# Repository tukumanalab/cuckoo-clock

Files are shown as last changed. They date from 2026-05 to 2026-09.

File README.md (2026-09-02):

# 鳩時計カムジェネレーター

3Dプリンターで製作できるオルゴール（ミュージックボックス）用カムの STL ファイルを、ブラウザ上で生成する Web アプリです。

**[大人の科学マガジン　あたらしい鳩時計](https://hon.gakken.jp/book/1575098600)（学研）の付録に付いているオルゴール機構で使えるカムのジェネレーターです。** このキットの機構にそのままセットできる寸法でカムを出力します。

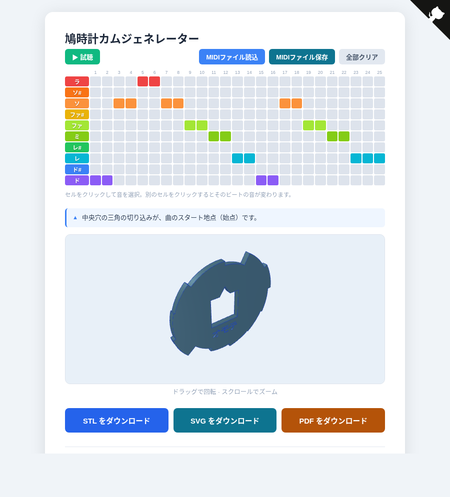
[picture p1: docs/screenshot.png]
アプリのスクリーンショット


## 概要

オルゴール機構の「琴爪（きんそう）」は、カムの歯（突起）の高さに応じてどの音が鳴るかが決まります。このアプリでは 25 分割されたカムの各セクターに音符を割り当て、好みのメロディを奏でるカムを設計・出力できます。

## 使い方

1. ブラウザで `index.html` を開く（静的 HTTP サーバーで配信）
2. ピアノロールのセルをクリックして 25 ビートに音を割り当て
3. 「▶ 試聴」でメロディを Web Audio で確認
4. 「STL をダウンロード」で 3D プリント用ファイル（`melody_cam.stl`）を取得
5. 3D プリンターでプリントし、オルゴール機構にセット

### UI 要素

| 要素 | 内容 |
|---|---|
| ピアノロール | 縦軸＝10 段階の音（半音階・ラ〜ド）、横軸＝25 ビート |
| セルクリック | そのビートに音を割り当て／同じセルを再クリックで休符（直前の音と同じ径） |
| ▶ 試聴 | 全 25 ビートを再生（triangle 波）。テンポは初期 ♩=300、MIDI 読込後はそのテンポ |
| MIDIファイル読込 | MIDI（SMF）を読み込んでピアノロールへ反映（1 拍 = 4 分音符、ラ〜ドへオクターブ畳み込み） |
| MIDIファイル保存 | 現在のメロディを MIDI（`melody.midi`、25/4 拍子・試聴と同じテンポ）として書き出し |
| 全部クリア | 全ビートを休符にリセット |
| 3D プレビュー | ドラッグで回転 · スクロールでズーム |
| STL をダウンロード | 現在のメロディをカム形状（STL）として書き出し |

## カム仕様

| パラメーター | 値 |
|---|---|
| セクター数 | 25 等分 |
| 厚さ | 1.8 mm |
| 中央穴 | 10.5 × 10.5 mm 正方形 |
| 開始マーカー | 正方形穴の +X 方向の壁に V字溝（幅 1.0mm・深さ 1.5mm） |

中央の正方形穴は、オルゴール機構の回転軸に取り付けるためのものです。V字溝がある側がセクター 1（メロディの最初の音）の開始位置です。

## 歯の高さ（外径）と音階の関係

オルゴール機構では**外径が大きいほど高い音**が鳴ります。琴爪の長さが外径によって決まり、短い琴爪ほど高周波で振動するためです。

この機構は **φ30〜φ40mm の範囲であれば、どの外径でも音が鳴る** 連続構造になっています。離散的な「5 つの琴爪」が並んでいるわけではなく、歯の高さに応じてピッチが連続的に変化します。本アプリではこの範囲を 10 段階に等分割して、半音階の「鍵盤」としてピアノロールに並べています。

| ノート番号 | 階名 | 外径 | 半径（コード値） | 試聴音（ドレミ／音名／周波数） |
|---|---|---|---|---|
| 0 | ラ | φ40.00 mm | 20.000 mm | ラ4 / A4 / 440 Hz |
| 1 | ソ# | φ38.75 mm | 19.375 mm | ソ#4 / G#4 / 415 Hz |
| 2 | ソ | φ37.50 mm | 18.750 mm | ソ4 / G4 / 392 Hz |
| 3 | ファ# | φ36.67 mm | 18.333 mm | ファ#4 / F#4 / 370 Hz |
| 4 | ファ | φ35.83 mm | 17.917 mm | ファ4 / F4 / 349 Hz |
| 5 | ミ | φ35.00 mm | 17.500 mm | ミ4 / E4 / 330 Hz |
| 6 | レ# | φ33.75 mm | 16.875 mm | レ#4 / D#4 / 311 Hz |
| 7 | レ | φ32.50 mm | 16.250 mm | レ4 / D4 / 294 Hz |
| 8 | ド# | φ31.25 mm | 15.625 mm | ド#4 / C#4 / 277 Hz |
| 9 | ド | φ30.00 mm | 15.000 mm | ド4 / C4 / 262 Hz |

### ⚠ 試聴音と実機の音は別物です

ピアノロールで「ラ」と打ち込むと、ブラウザは **A4＝440Hz** を鳴らしますが、実機のカムが鳴らすのは **A4 ではありません**。試聴と実機の音は、次の 2 つの点で違います。

#### ① オクターブが約 3 つ違う

実機の音は **第 7 オクターブ**（2400〜3800Hz）の高音域です。機構が小型で琴爪が短いため、固有振動数が高くなります。ブラウザ試聴は耳に優しい **第 4 オクターブ**（中央ハ周辺、262〜440Hz）に置いていて、メロディの形（上がる／下がる／繰り返し）を確認するためのものです。

#### ② 音の並び方が違う（試聴と実機で「ラ」が指す音が違う）

ピアノロールの「ラ」「ソ」「ミ」「ド」… は **ピアノの白鍵・黒鍵に揃えた音の並び**（音楽でいう「平均律」）です。これは人間の耳に馴染みがあり、メロディが綺麗に聞こえるように人工的に整えてあります。

一方、実機は金属パーツを物理的に振動させて鳴らす機構なので、出る音は機構の形状や材質で勝手に決まります。φ40mm を「ラ」のつもりで打ち込んでも、実機が出すのは「ラ（A）」ではなく **少し高い「シ♭（Bb）」**。同様に「ミ」のつもりが「ソ#」、「ド」のつもりが「レ」のあたり、というふうに、**全部ズレた音名で鳴ります**。

#### でもこれで OK な理由

「ピアノロールの音名と実機の音が一致しないなら、試聴は何のためにあるの？」と思うかもしれません。これで OK な理由は：

- **メロディは「音の名前」ではなく「音の上下のパターン」で認識される。** たとえば「ド ド ソ ソ ラ ラ ソ」を全体的に半音や全音ずらしても、上がる場所・下がる場所・繰り返す場所が同じなら、人は **同じキラキラ星** だと聞き取れます。カラオケで自分のキーに合わせて歌っても曲が変わらないのと同じです。
- アプリの試聴も実機も、**外径が大きい歯ほど高い音、小さい歯ほど低い音** という性質は共通しています。だから「ピアノロールで聞いて気持ちよく流れたメロディ」は、実機でもだいたい同じ上下のパターンで流れます。
- 試聴の役割は「**メロディの形（ジングルの感じ）**」を耳で確認すること。「**絶対的にこの音が鳴る**」ことを約束するものではありません。

なお、実機の音は平均律ではないので、**ピアノロール上の音間隔と実機の音間隔は完全には一致しません。** たとえば試聴で「ドとソは 5 度離れている」と聞こえても、実機では同じ 2 か所が「5 度よりやや狭い」「半音ほど広い」など微妙にズレることがあります。それでも「上がる・下がる・繰り返す」の骨格は保たれるので、メロディとして認識できる、というのが基本的な発想です。

### 休符の扱い

カム上に「休符」という概念はありません。エディター上で何も選択していないビート（休符）は、STL 出力時に**直前のビートと同じ外径**として扱われます。これによりすべてのセクターが機構に確実にかかり、同じ音が連続して鳴る形になります。

### 実測値（参考）

5 つの代表的な外径について、単音テストカムを実機にかけてマイクで録音・解析した結果です。この 5 点は機構が出せる音の **代表サンプル** であり、間の径（例：φ36.67mm）でも音は鳴ります（連続的に変化します）。

| 外径 | 実測音名（ドレミ／音名） | 代表周波数 | 備考 |
|---|---|---|---|
| φ40mm | **シ♭7（ラ#7） / Bb7（A#7）** | ~3709 Hz | ボディ共鳴との差分で同定 |
| φ37.5mm | ファ#7 / F#7（参考値） | ~2980 Hz | 5音サイクルカムからの推定 |
| φ35mm | **ソ#7（ラ♭7） / G#7（Ab7）** | ~3406 Hz | 非常に安定した測定値 |
| φ32.5mm | 未同定 | 不安定 | サイクルごとにスペクトル変動 |
| φ30mm | **レ7〜レ#7 / D7〜D#7** | ~2420 Hz | D7 より約 +30¢ 高め |

- φ40mm と φ35mm はどちらも G#7 付近（~3350 Hz）に強いピークを持ちますが、これは機構本体の**ボディ共鳴（胴鳴り）**です。φ40mm 固有の音は差分スペクトルで求めた Bb7（~3710 Hz）です。
- φ32.5mm の音名が「未同定」なのは、機構が鳴らないからではなく、サイクルごとに測定スペクトルが変動して安定したピークを特定できなかったためです。
- 解析ツール: Python + soundfile + scipy（macOS `afconvert` で m4a → WAV 変換）

## デフォルトメロディ（キラキラ星）

起動時のメロディは「キラキラ星」（25 ビート）です：

```
ビート 1– 8: ド ド ソ ソ ラ ラ ソ ソ
ビート 9–16: ファ ファ ミ ミ レ レ ド ド
ビート17–25: ソ ソ ファ ファ ミ ミ レ レ レ
```

## ファイル構成

```
cuckoo-clock/
├── index.html        # HTML マークアップ
├── style.css         # スタイルシート
├── app.js            # Three.js プレビュー + STL 生成 + UI ロジック
├── docs/
│   └── screenshot.png  # README 用スクリーンショット
└── README.md         # このファイル
```

## 動作環境

- モダンブラウザ（Chrome / Firefox / Safari / Edge）
- ES Modules と importmap をサポートする環境
- Three.js は CDN（jsdelivr）から読み込み（インターネット接続が必要）

ローカルで動作させる場合は HTTP サーバーが必要です：

```bash
python3 -m http.server 8080
# または
npx serve .
```

## ライセンス

MIT

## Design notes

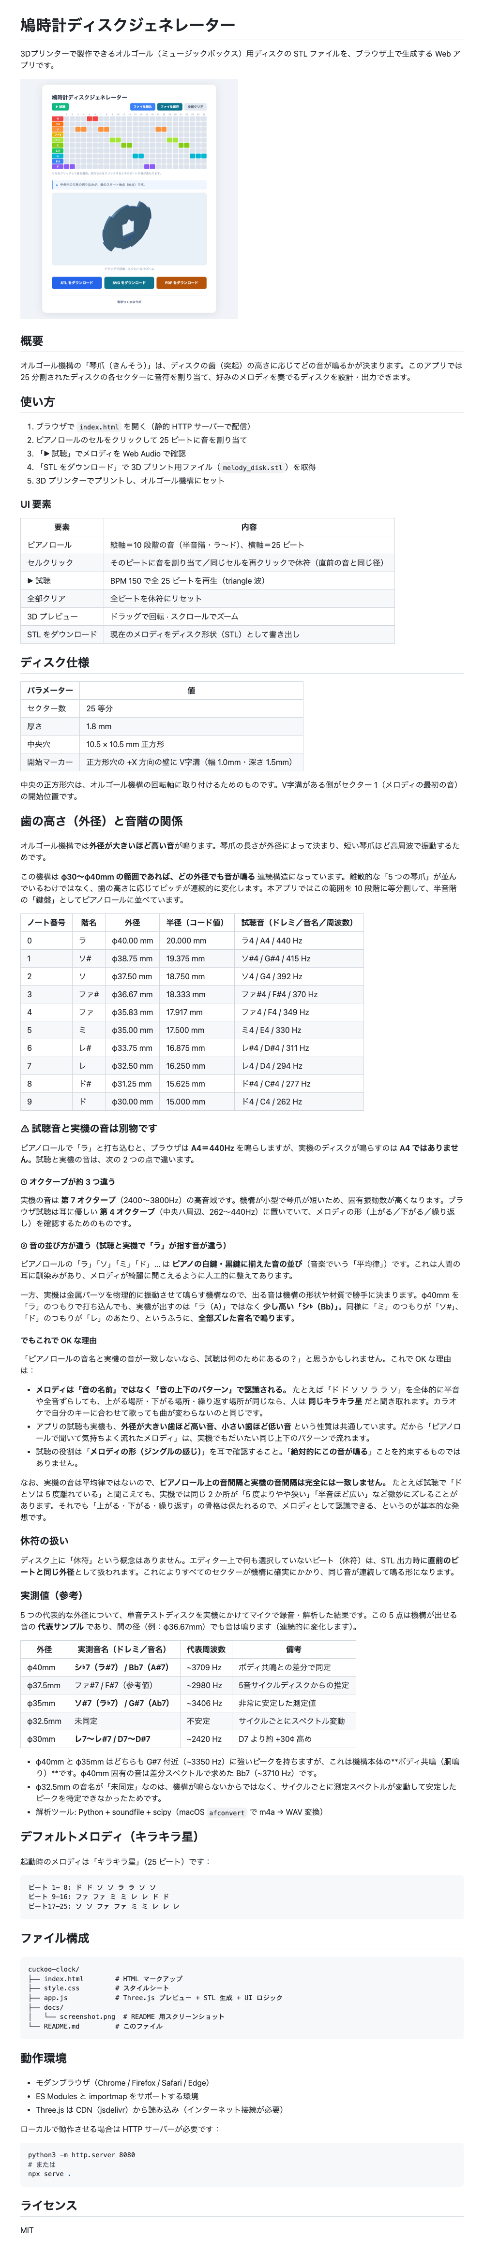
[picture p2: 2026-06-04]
docs/github.png

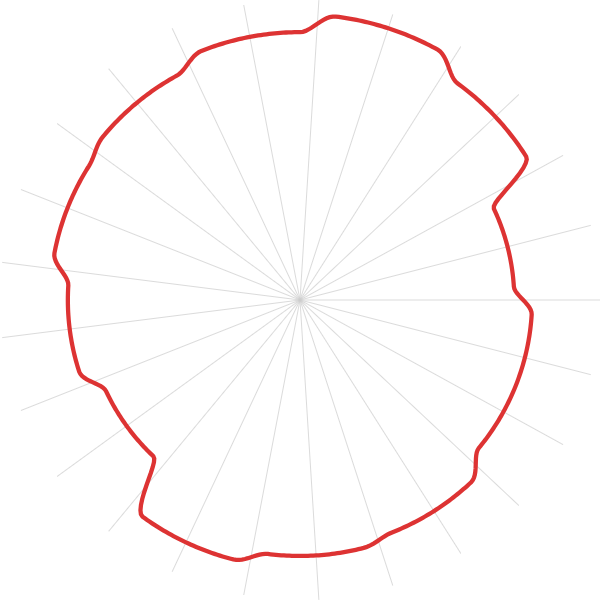
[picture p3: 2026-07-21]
pr-images/cam-svg-outline.png

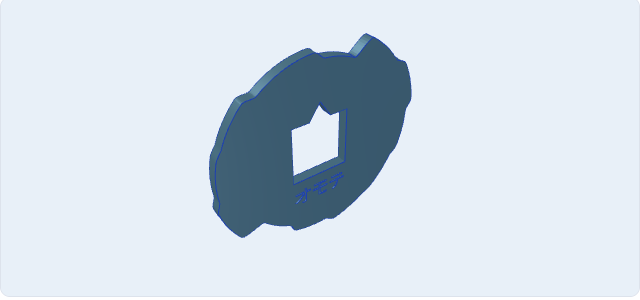
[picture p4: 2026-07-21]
pr-images/cam-3d-preview.png

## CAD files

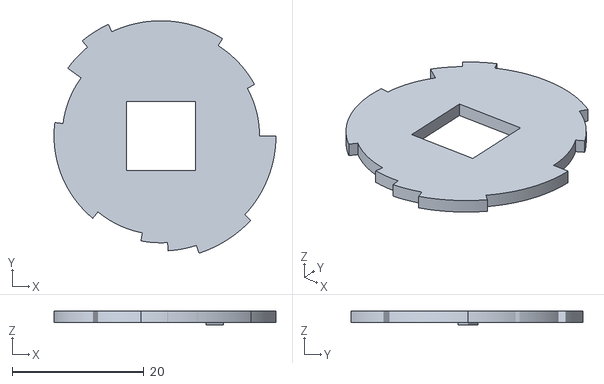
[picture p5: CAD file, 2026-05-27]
stl/poppo.stl
33.8 x 35.3 x 2.20

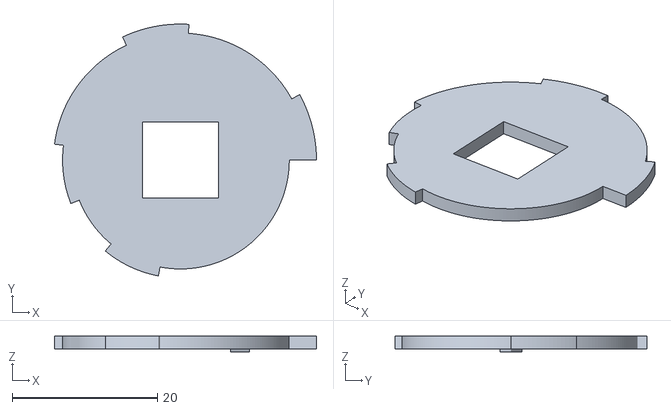
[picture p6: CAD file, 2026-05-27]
stl/kakko.stl
36.1 x 34.7 x 2.20

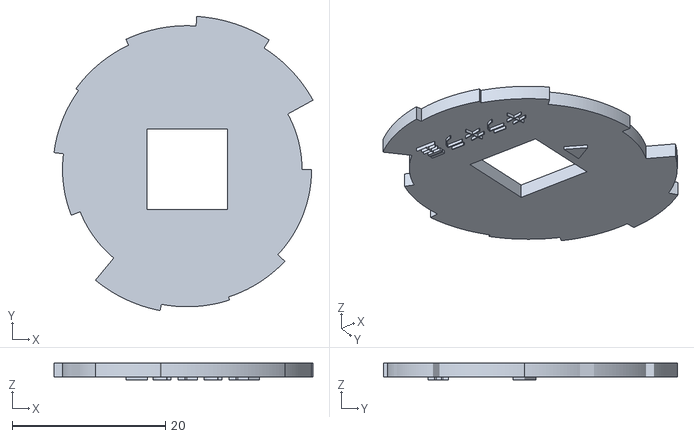
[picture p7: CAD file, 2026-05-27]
stl/kirakira.stl
33.8 x 38.4 x 2.20

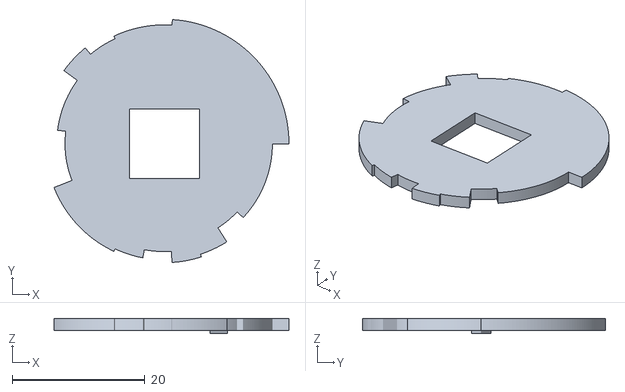
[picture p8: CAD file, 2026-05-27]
stl/hinotori.stl
35.4 x 36.6 x 2.20

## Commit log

2026-05-22 Initial commit: music box disk STL generator
    - STL generator for 3D-printable music box (オルゴール) disks
    - Three.js interactive 3D preview
    - Melody mode with 24-beat sequencer (キラキラ星 default)
    - Start groove marker on square center hole at sector 0
    - Single-note test disks (φ40/35/30mm)
    - CSS and JS split into separate files
2026-05-22 Rename app title to 鳩時計ディスクジェネレーター
2026-05-22 Show solfège (ドレミ) on melody beat buttons
2026-05-22 Remove single-note test disk buttons (φ40/35/30mm)
2026-05-22 ピアノロール UI を実装し12音クロマチック対応・休符廃止
    - ピアノロール UI（縦12音×横25拍のステップシーケンサー）を実装
    - 12音クロマチックスケール（ド〜シ）をサポート：各音に固有のディスク外径を設定
    - ファ/ファ#/ソ#/レ#/ド# は既知5点間を半音基準で線形補間
    - シ/ラ# は物理限界（φ40mm）に頭打ち
    - 休符廃止：各ビートは常に音を持つ（クリックで音を選択）
    - キラキラ星メロディを25拍・正しい音階に更新（ファを含む）
    - スペックテーブルを削除
    - ピアノロールのはみ出し修正：グリッド列数をJSで動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
2026-05-22 ラ# とシを音リストから削除（物理的に出力不可）
    10音クロマチック（ラ〜ド）に変更。キラキラ星のインデックスも更新。
2026-05-22 最後のビートを休符に変更・キラキラ星ダウンロードボタンを削除
    - DEFAULT_MELODY の最終ビート(25番)を休符(-1)に変更（STL出力時は直前のレを繰り返す）
    - 休符トグルを復活：アクティブなセルをクリックすると休符になる
    - キラキラ星専用ダウンロードボタン(dlTwinkle)を削除
2026-05-22 最終ビートをレに変更
2026-05-22 「♪ キラキラ星」タイトルを非表示に
2026-05-22 コードを簡素化（349行→265行）
    - 未使用の markerObj / REST_R / getRadiiSeq / noteSeqToRadii / downloadSTL / playNote / getCtx を削除
    - generateSTL の customSeq / addMarker 引数を廃止（V溝マーカーは常時付与）
    - playBtn ハンドラーをインライン化、audioCtx を nullish assignment で初期化
    - downloadBtn ハンドラーをインライン化
2026-05-22 「全部クリア」ボタンを追加
    全ビートを休符にリセットするボタンを試聴ボタンの隣に配置。
2026-05-23 README を現状のコードに合わせて更新
    10 段階半音階・25 ビート・単一画面 UI を反映し、試聴音にドレミ／音名／周波数を併記。
2026-05-23 README にアプリのスクリーンショットを追加
    ピアノロール（キラキラ星デフォルト）と 3D プレビューが写ったキャプチャを
    docs/screenshot.png として配置し、README 冒頭で表示。
2026-05-23 README の音階説明を訂正・スクリーンショットを半分にリサイズ
    機構は φ30〜φ40mm の連続構造で、どの外径でも音が鳴ることを明記。
    試聴音（平均律・第 4 オクターブ）と実機音（機構固有音律・第 7 オクターブ）
    の差を 2 軸で整理。スクリーンショットは 1800×2200 → 900×1100 に縮小。
2026-05-23 平均律の説明を非音楽家向けに書き直し・キャプチャをさらに半分に
    「平均律」を「ピアノの鍵盤に揃えた音の並び」と言い換え、なぜ試聴と
    実機の音名がズレても OK なのかをカラオケのキー変更の例で説明。
    スクリーンショットは 900×1100 → 450×550 にリサイズ。
2026-05-23 実測値表にドレミ表記を併記
    シ♭7／ファ#7／ソ#7／レ7〜レ#7 を Bb7 / F#7 / G#7 / D7〜D#7 と
    並べて表示し、音楽記号に不慣れな読者にも読みやすく。
2026-05-27 表側を示す三角形マーカーを追加
    ディスク上面（表）の中央穴上方に正三角形の突起（辺長3mm・高さ0.4mm）を追加。
    STL出力・3Dプレビュー両方に反映。
2026-05-27 表面（z=0面）に「オモテ」の刻印を追加
2026-05-27 オモテ文字刻印を三角突起に変更（V字溝と同方向）
2026-05-27 裏面の三角突起とV字溝を削除、初期表示を表側に変更
2026-05-27 刻印テキスト入力機能を追加（日本語対応、リアルタイムプレビュー）
    - opentype.js + Noto Sans JP でテキストを3Dジオメトリ化
    - STLExporter に置き換えてテキスト含む全メッシュを出力
    - sp.closePath() → sp.currentPath?.closePath() で TypeError を修正
    - X座標を反転し鏡文字を修正（カメラ-Z視点の座標系補正）
    - フォント読み込み後に「キラキラ星」をデフォルト値として表示
2026-05-27 刻印テキスト入力機能を削除
2026-05-27 STLサンプルファイルを追加
    [hinotori.stl, kakko.stl, kirakira.stl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]
2026-05-27 poppo.stl を更新
    [poppo.stl]
2026-06-02 SVG ダウンロード機能を追加
    レーザーカットや型紙用に、ディスク外周輪郭と中央穴（V溝マーカー付き）を
    含む SVG を出力するボタンを追加。.DS_Store も gitignore に追加。
2026-06-02 SVG を塗りつぶしなしの枠線のみに変更
    レーザーカット/型紙用途に合わせ、fill を none にして外周輪郭と中央穴を
    カットライン（黒 0.1mm）だけで出力。fill-rule による穴抜きは不要のため削除。
2026-06-02 ドレミ txt 入出力・SVG/PDF 出力・始点/オモテ表示を追加
    - ドレミ txt の読み込み/保存（parseSolfege / melodyToSolfege）
    - 始点の三角切り込み（曲のスタート地点。中央穴 +X 側、サイズ調整）
    - 「オモテ」表示用の貫通穴を中心の下に追加（表面で正立、Arial Unicode から抽出）
    - 始点を画面の上（+Y）に向ける表示回転（3D / SVG / PDF）
    - 枠データの SVG / PDF ダウンロード（PDF は A4 左上・原寸・表面像）
    - PDF 楽譜→ドレミ判読ロジックを CLAUDE.md に記録、sound_files/ に AMA2・FAN2 を配置
    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
2026-06-03 GitHub リボンとフッターリンクを追加
2026-06-04 ボタン名をファイル読込/ファイル保存に変更し README キャプチャを更新
    - index.html: 「ドレミ読込/ドレミ保存」→「ファイル読込/ファイル保存」
    - docs/screenshot.png: 最新 UI（始点バナー・SVG/PDF ボタン含む）で再撮影
    - CLAUDE.md: ボタン名の記述を更新
    - .claude/skills/run-app: アプリ起動とスクリーンショット撮影のプロジェクトスキルを追加
2026-06-04 README キャプチャを半分のサイズに縮小し README 全体のキャプチャを追加
    - docs/screenshot.png を 900x995 → 450x497 にリサイズ
    - README をレンダリングしたキャプチャを docs/github.png として追加
2026-06-04 メロディの読み書きをドレミ txt から MIDI ファイルに変更
    - ボタン名を「MIDIファイル読込」「MIDIファイル保存」に変更
    - SMF format 0/1 のパーサー（parseMidi）を実装。全トラックのノートオンを
    1 拍 = 4 分音符でセクターに割り当て、音のない拍は休符
    - 音高はオクターブ畳み込みでラ〜ド（A〜C の 10 半音）へ対応付け、
    範囲外・25 拍超過・同一拍重複は無視して件数を alert 通知
    - 保存（melodyToMidi）は format 0・480tpq・25/4・4 分音符・A5〜C5 で出力
    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
2026-06-04 README キャプチャを以前と同じ半分サイズ（450×497）に縮小
2026-06-23 ディスクという呼称をカムに変更
    タイトル「鳩時計ディスクジェネレーター」を「鳩時計カムジェネレーター」に変更し、
    プロジェクト全体（index.html / app.js / README.md / CLAUDE.md / SKILL.md）の
    「ディスク」表記を「カム」へ統一。出力ファイル名も melody_disk.* から
    melody_cam.* に変更。
2026-06-23 README キャプチャをカム表記に差し替え
    タイトル変更（鳩時計ディスクジェネレーター → 鳩時計カムジェネレーター）に
    合わせて docs/screenshot.png を再撮影。サイズは従来通り 450×497。
2026-07-21 カム外周の段差を smoothstep でなだらかにして音飛びを解消
2026-08-12 WebGL 不可の環境でもエディタと STL 出力が動くようにする
    Chrome のハードウェアアクセラレーションが無効な環境では
    new THREE.WebGLRenderer() が例外を投げ、app.js（単一 ES モジュール）の
    評価がそこで止まっていた。結果としてピアノロールの構築も各ボタンの
    イベント登録も実行されず、音符エディタが表示されずアプリがほぼ全滅していた。
    renderer の生成を try/catch で包み、失敗時は 3D プレビューだけを諦めて
    案内文を出す。scene / camera / ライトは STLExporter が使うため常に生成し、
    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
2026-09-02 README に対象製品（大人の科学マガジン あたらしい鳩時計）を記載
    Claude-Session: https://claude.ai/code/session_011kcJftWjB838diDSt6w7Ay
2026-09-02 アプリ画面に README 冒頭の説明文を表示
    タイトル直下に .subtitle 段落を追加し、大人の科学マガジン
    あたらしい鳩時計（学研）の付録機構向けであることを明記。
    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
